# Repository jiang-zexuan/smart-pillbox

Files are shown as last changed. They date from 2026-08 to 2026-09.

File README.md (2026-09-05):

# 自动分药系统（Smart Pillbox）

基于 STM32 的自动分药系统，由 Android 应用、STM32 固件、Bluetooth SPP/RFCOMM 通信和参数化外壳组成。仓库包含 CadQuery/Python 参数化模型源文件及 STEP/STL 三维模型。

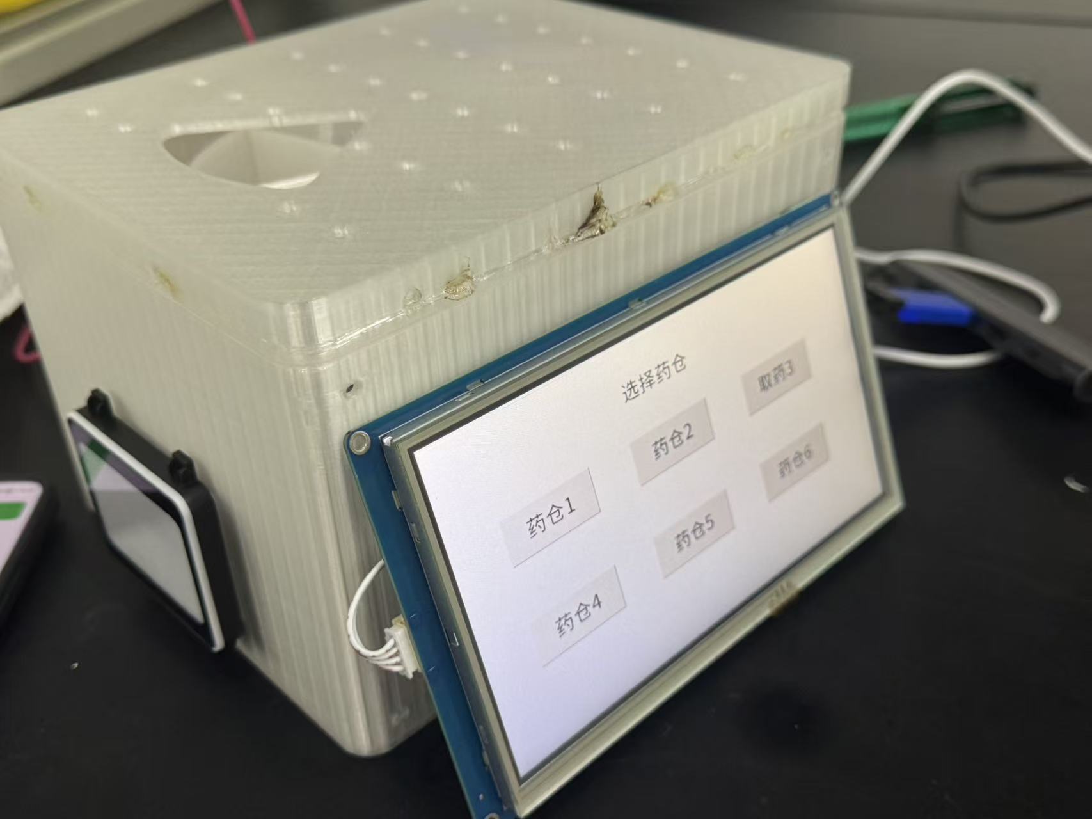
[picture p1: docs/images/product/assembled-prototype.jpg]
实物原型


## 实物与结构展示

### 实物原型

系统装配完成后的整体外观，包含分药转盘、显示屏和扫码区域。

自动分药系统实物原型

### 外壳打印

参数化外壳的打印与装配效果。

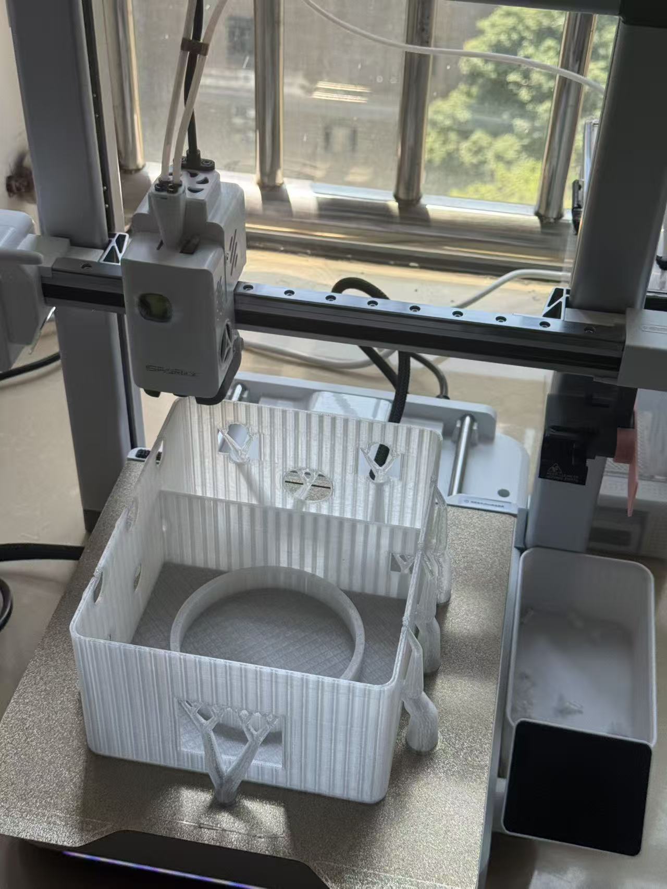
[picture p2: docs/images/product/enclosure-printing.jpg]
自动分药系统外壳打印


### 内部电子器件

内部控制板、蓝牙模块、称重模块及其他外设的安装状态。

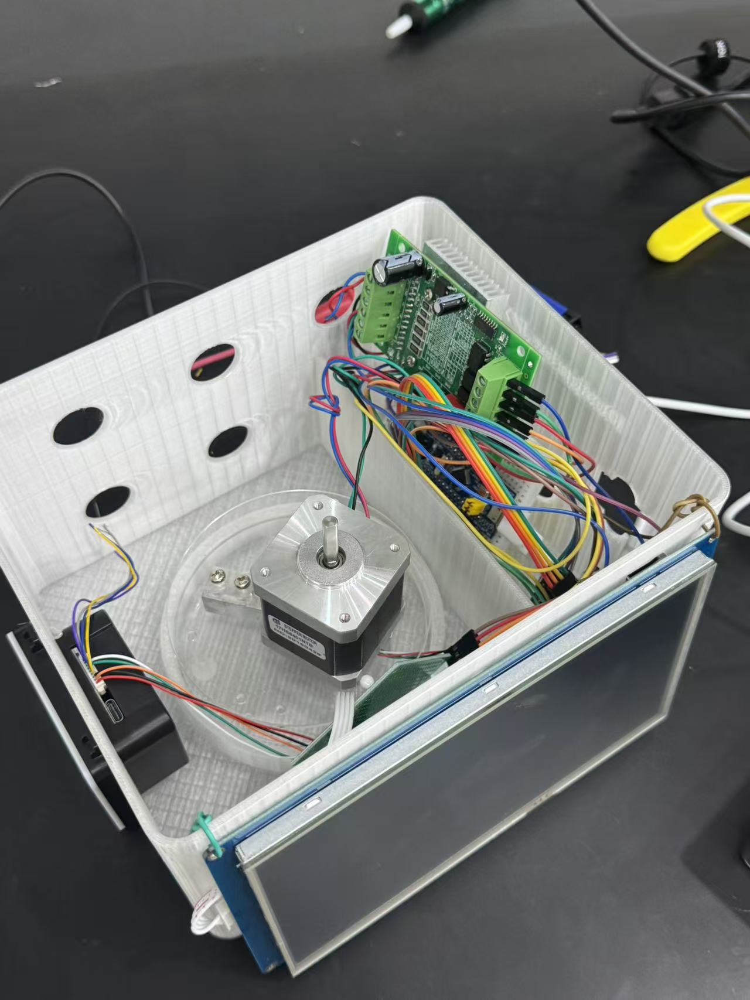
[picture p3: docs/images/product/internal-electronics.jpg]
自动分药系统内部电子器件


### 三维结构总览

CAD 模型展示系统整体结构与各部件的空间关系。

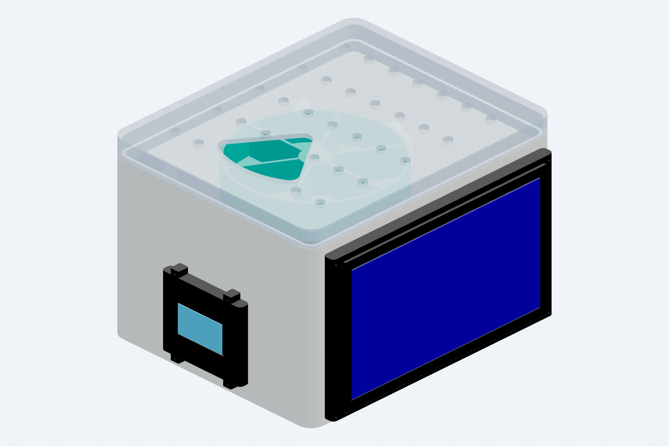
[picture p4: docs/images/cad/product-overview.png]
自动分药系统三维结构总览


### 正面扫码与显示区域

正面视图展示 QR100 扫码器、显示屏和人机交互区域。

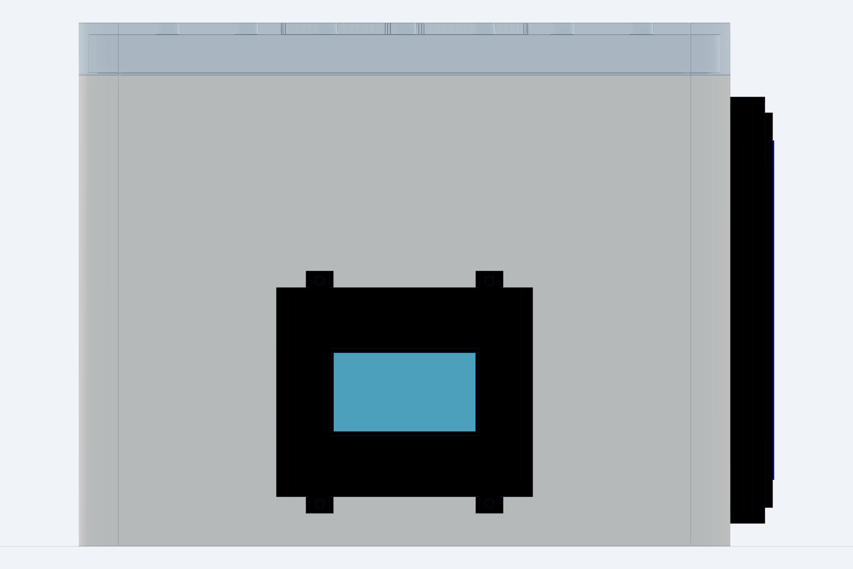
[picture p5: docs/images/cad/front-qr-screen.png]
自动分药系统正面扫码与显示区域


### 内部布局

CAD 剖视布局展示转盘、电子器件与外壳内部的安装关系。

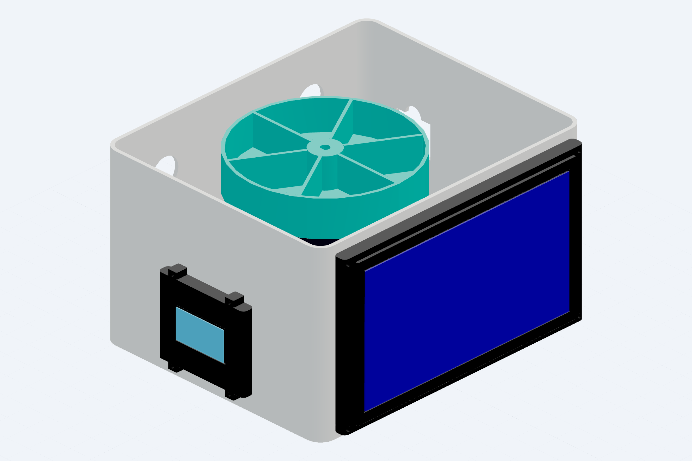
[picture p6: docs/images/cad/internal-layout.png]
自动分药系统内部布局


## 系统组成

系统由 Android 应用、STM32 固件、Bluetooth SPP/RFCOMM 通信链路和参数化外壳构成，实现定时提醒、自动出药、称重检测、漏服记录与手机端管理等完整功能。

## 核心功能

- Android `BleManager` 基于标准 SPP UUID，通过 RFCOMM Socket 完成蓝牙扫描、连接、自动重连与分行数据收发，下发 `TIME`、`PLAN`、`SET`、`MOTOR`、`SYNC` 五类控制命令。
- STM32 固件 `src/protocol.c` 实现命令解析与分派，驱动 HMI/OLED 显示、QR100 扫码、HX711 称重、蜂鸣器提醒和步进电机出药机构。
- 步进电机转盘支持 6 仓位定位，采用最短路径算法与相对位置追踪。
- HX711 称重模块通过滑动平均滤波与零点校准实现取药检测，重量下降超过阈值即判定为已服药。
- 服药记录持久化存储于 STM32 内部 Flash，循环写入并带校验和，上电自动恢复。
- PlatformIO 支持 `bluepill_f103c8` 固件构建，配套电机命令静态检查脚本与仓库规范单元测试。

## 目录结构

| 路径 | 内容 |
| --- | --- |
| `android/` | Android Studio/Gradle 应用源码（Kotlin）。 |
| `firmware/` | STM32Cube HAL、PlatformIO 工程、通信协议与外设驱动源码。 |
| `mechanical/src/` | CadQuery/Python 参数化模型源文件。 |
| `mechanical/models/` | STEP/STL 三维模型文件，可直接用于 3D 打印。 |
| `docs/` | [系统架构](docs/architecture.md)、[通信协议](docs/protocol.md) 及配图。 |
| `tests/` | 仓库规范检查脚本与单元测试。 |

## 构建与验证

### 固件构建（PlatformIO）

```powershell
cd firmware
pio run
python tools_check_motor_command.py
```

### Android 应用构建

需配置 JDK 与 Android SDK 环境后执行：

```powershell
cd android
.\gradlew.bat test
```

### 仓库规范检查

```powershell
python -m unittest discover -s tests -v
```

固件构建、电机命令静态检查与全部 6 项仓库规范单元测试均通过。

## 许可证与版权

软件源码（`android/`、`firmware/`）采用 MIT License；硬件/CAD（`mechanical/`）采用 CERN-OHL-P-2.0。完整法律文本在 [`LICENSES/`](LICENSES/)。实物照片和说明文字由作者保留版权，除非另有书面许可。

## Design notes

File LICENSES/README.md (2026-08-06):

# 许可证说明

- 软件源码（`android/`、`firmware/`）采用 MIT License，完整文本见 [MIT.txt](MIT.txt)。
- 硬件相关源码与 CAD 模型（`mechanical/`）采用 CERN Open Hardware Licence Version 2 - Permissive，完整文本见 [CERN-OHL-P-2.0.txt](CERN-OHL-P-2.0.txt)。
- `docs/images/product/` 中的实物照片以及项目说明文字为作者保留版权，除非另有书面授权，不随上述软件/硬件许可证自动授予再利用权。

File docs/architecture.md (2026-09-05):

# 系统架构

自动分药系统由 Android 应用、经典蓝牙串口链路和 STM32 固件组成。应用通过 Bluetooth SPP 的 RFCOMM socket 与 JDY-31 类串口蓝牙模块通信；模块的 UART 接到 STM32。固件再驱动屏幕、人机界面、二维码扫描器、蜂鸣器、HX711 称重和步进电机。

```text
Android UI / 本地存储
        |
        | Bluetooth SPP (RFCOMM, UUID 00001101-0000-1000-8000-00805F9B34FB)
        v
JDY-31 经典蓝牙串口模块
        |
        | UART, CRLF 分行文本
        v
STM32F103C8T6 firmware
        +--> TJC8048X270 HMI / OLED
        +--> QR100 scanner
        +--> HX711 load-cell sensor
        +--> buzzer and stepper motor
```

## 数据流

应用负责扫描/选择设备、建立 RFCOMM socket、按 CRLF 发送命令并解析回执。固件在主循环中逐行读取 UART，交给 `src/protocol.c` 分派；状态、服药记录和提醒通过同一链路回传。系统时间由应用通过 `TIME` 命令同步，同时支持切换为 DS3231 硬件 RTC。

## 构建边界

- Android：`android/` 是 Gradle Android application，目标 SDK 34，最低 SDK 24。
- Firmware：`firmware/platformio.ini` 使用 `bluepill_f103c8`、STM32Cube framework；`Core/` 与 `Drivers/` 是 HAL/CubeMX 支持树，`include/src` 是 PlatformIO 当前编译入口。
- Mechanical：`mechanical/src/` 保存 CadQuery/Python 参数化模型源，`mechanical/models/` 包含发布用 STEP/STL 输出。

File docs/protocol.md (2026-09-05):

# 串口协议

传输为 Bluetooth SPP/RFCOMM 字节流，Android 每条命令追加 `\\r\\n`，STM32 按行解析。下表列出 Android 与 STM32 源码中使用的业务命令。

| 命令 | 格式 | 固件行为 / 回执 |
| --- | --- | --- |
| `TIME` | `TIME:<unix_timestamp>` | 设置软件时钟；回 `TIME_ACK:<timestamp>`。 |
| `PLAN` | `PLAN:<slot>,<hh>,<mm>,<period>,<enabled>` | 校验 6 个仓位、时间和时段，保存计划；回 `PLAN_ACK:...`。 |
| `SET` | `SET:<slot>,<medicine_name>` | 写入药品名称并更新仓位状态；回 `SET_ACK:...`，启用电机时还回 `MOTOR_ACK:SET_SLOT,...`。 |
| `MOTOR` | `MOTOR:TEST`、`MOTOR:SLOT,<slot>`、`MOTOR:CW,<steps>`、`MOTOR:CCW,<steps>` | 在 `FEATURE_MOTOR_RESERVED=1` 时执行步进测试、转到仓位或按方向步进；回 `MOTOR_ACK:...`。源码将步数限制为 1..6400。 |
| `SYNC` | `SYNC:ALL` | 请求全量状态；固件调用 `BLE_SendStatus()` 回传状态/计划/仓位。 |

其它源码中出现的 `PING`、`TEST`、`BEEP`、`TARE`、`STAT`、`QR`、`REMIND`、`ALERT`、`REC` 属于心跳、调试或设备内部事件，不作为跨模块业务 API。

## 示例

```text
TIME:1780000000\r\n
PLAN:0,8,30,0,1\r\n
SET:0,Vitamin-C\r\n
MOTOR:SLOT,0\r\n
SYNC:ALL\r\n
```

协议采用 CRLF 分行文本格式，便于调试与跨平台解析；调用方应处理无回执、格式错误和设备断连等异常场景。

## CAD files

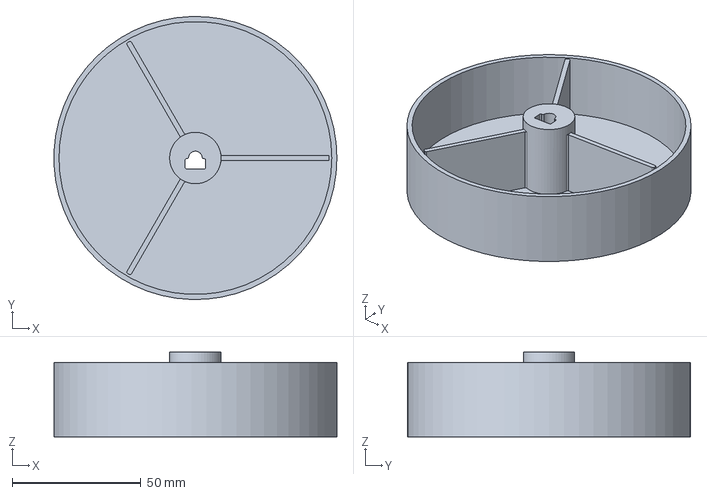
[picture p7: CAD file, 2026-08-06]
mechanical/models/smart_pillbox_turntable.step
109.9 x 110.0 x 33.0 mm

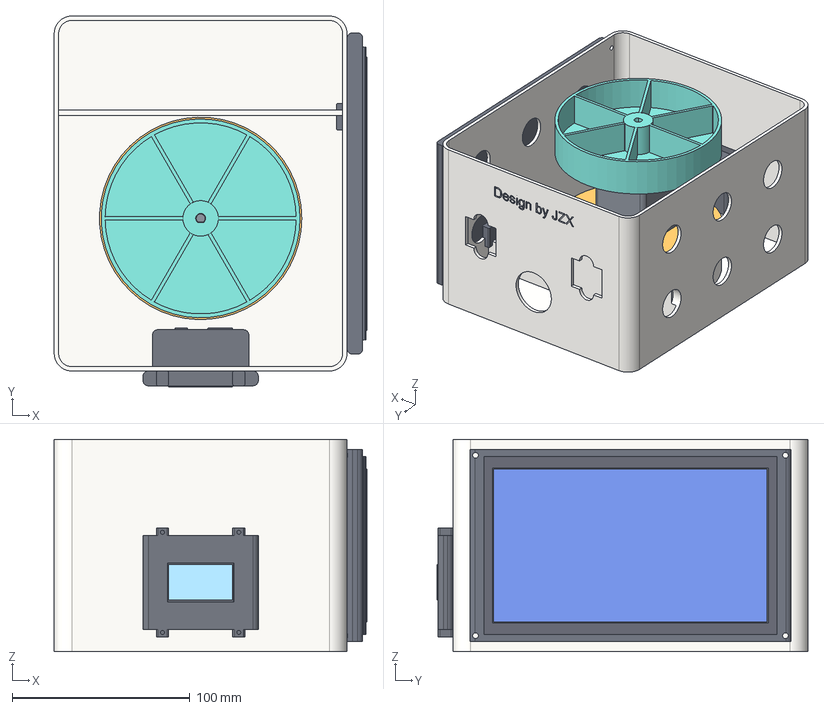
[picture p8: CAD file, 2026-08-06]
mechanical/models/smart_pillbox_colored_internal_no_lid.step
176.1 x 209.0 x 119.5 mm
warm_white_printed_base
silver_hx711_load_sensor_cylinder
amber_downward_open_motor_mount
graphite_nema17_stepper_motor
metallic_d_shaft_visual_overlay
teal_six_compartment_medicine_tray
black_zy_qr100_scanner
cyan_qr100_scan_window
dark_tjc8048x270_serial_screen
black_screen_bezel_overlay
blue_active_display_overlay

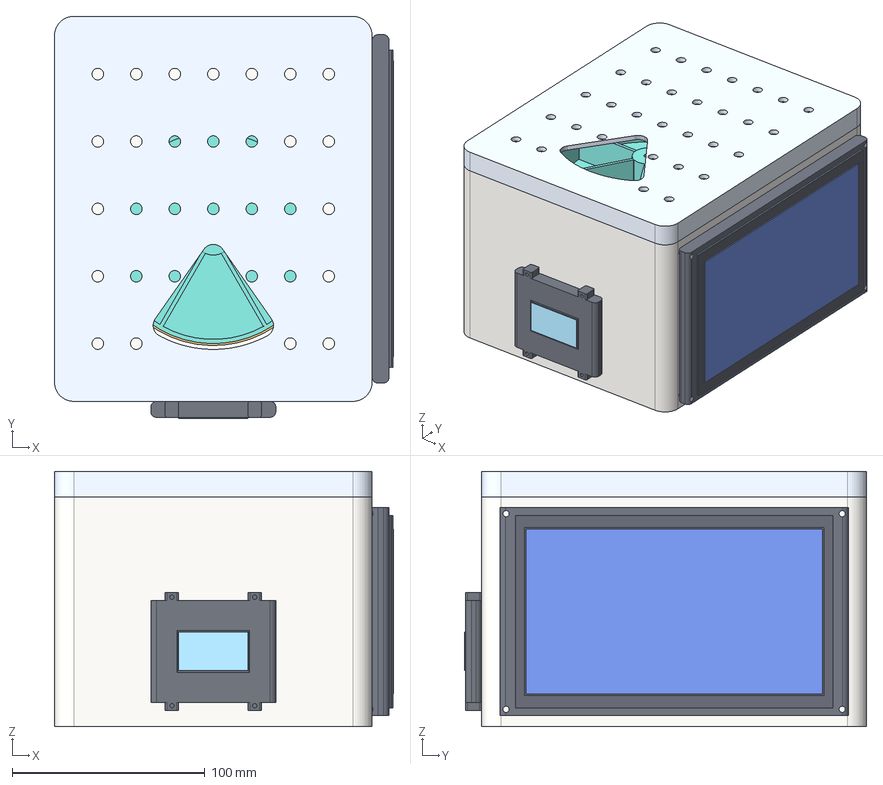
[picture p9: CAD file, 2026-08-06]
mechanical/models/smart_pillbox_colored_product_render.step
176.1 x 209.0 x 132.5 mm
warm_white_printed_base
silver_hx711_load_sensor_cylinder
amber_downward_open_motor_mount
graphite_nema17_stepper_motor
metallic_d_shaft_visual_overlay
teal_six_compartment_medicine_tray
pale_blue_raised_top_lid
black_zy_qr100_scanner
cyan_qr100_scan_window
dark_tjc8048x270_serial_screen
black_screen_bezel_overlay
blue_active_display_overlay

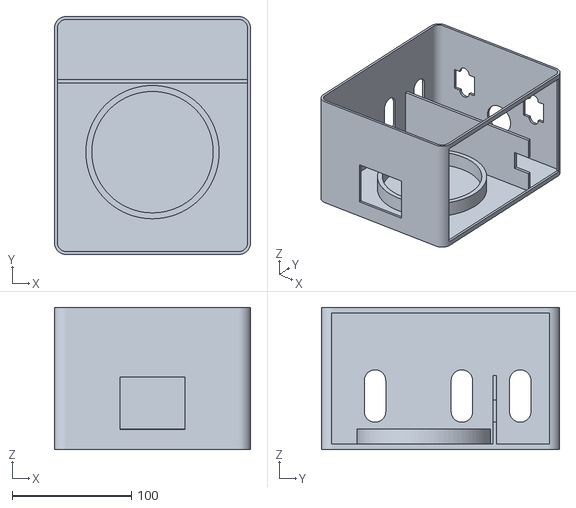
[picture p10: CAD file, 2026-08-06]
mechanical/models/smart_pillbox_base_lightweight_with_screen_opening.stl
165.0 x 200.0 x 119.5

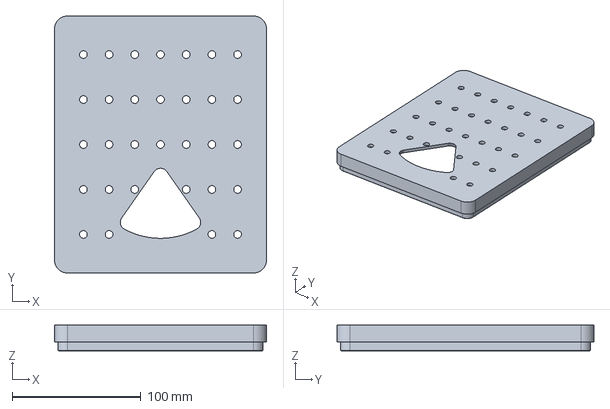
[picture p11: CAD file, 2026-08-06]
mechanical/models/smart_pillbox_top_lid.step
165.0 x 200.0 x 20.0 mm

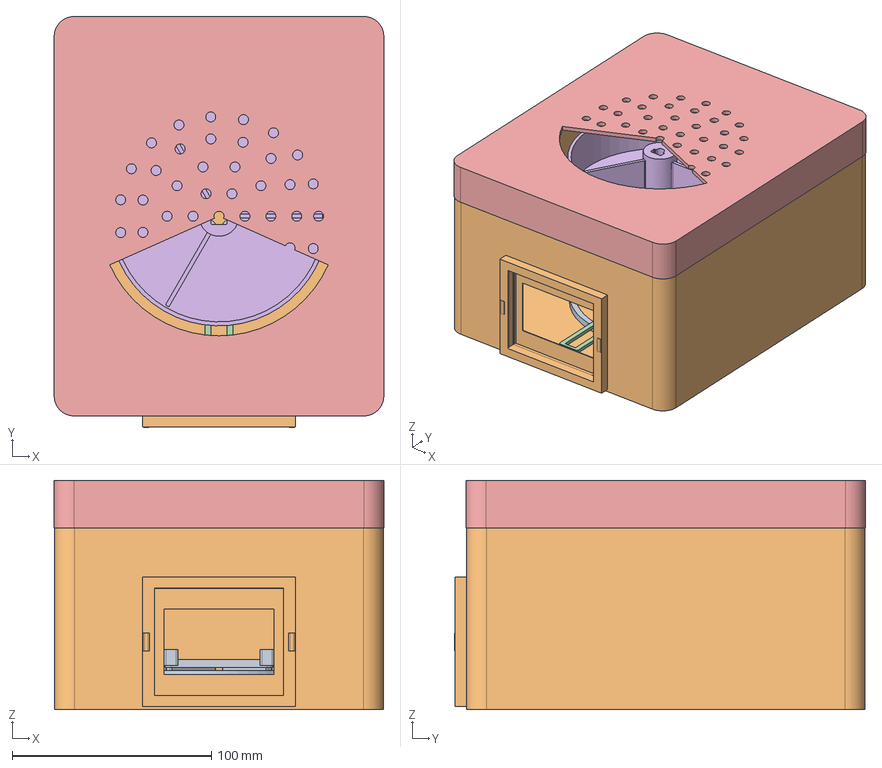
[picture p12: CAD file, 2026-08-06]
mechanical/models/smart_pillbox_printable.step
165.4 x 206.2 x 115.0 mm
base
lid
turntable

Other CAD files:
mechanical/models/smart_pillbox_top_lid.stl
mechanical/models/smart_pillbox_turntable.stl

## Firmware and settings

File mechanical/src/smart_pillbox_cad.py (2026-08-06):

"""
Smart pillbox CAD model.
Units: millimeters.
Coordinate system: origin at enclosure footprint center; X width left/right, Y depth front/back, Z up.

This file is generated for the smart pillbox course-design enclosure.
It exposes gen_step() for the full placeholder assembly.  Additional helper
functions are used by small wrapper files to export pure printable assembly
and individual printable parts.
"""
from __future__ import annotations

import inspect
import math
import platform

# Work around a build123d Windows font scan issue caused by malformed system fonts.
_REAL_PLATFORM_SYSTEM = platform.system

def _platform_system_patch():
    for fr in inspect.stack()[:10]:
        if fr.filename.replace("\\", "/").endswith("build123d/text.py"):
            return "Linux"
    return _REAL_PLATFORM_SYSTEM()

platform.system = _platform_system_patch

from build123d import *  # noqa: E402,F403
from cadpy.assembly import AssemblyHelper, label_shape  # noqa: E402

# -------------------------- Parameters --------------------------
OUTER_X = 165.0
OUTER_Y = 200.0
OUTER_Z = 115.0
WALL = 2.5
CLEARANCE = 0.4
CORNER_R = 10.0

BASE_H = 92.0
LID_H = 24.0
LID_SKIRT_H = 10.0
LID_TOP_TH = 3.0
LID_OVERLAP = 0.4

FRONT_Y = -OUTER_Y / 2
BACK_Y = OUTER_Y / 2

# QR100, based on the provided manual.
QR_FACE_W = 65.0
QR_FACE_H = 53.0
QR_FACE_TH = 8.3
QR_BODY_W = 54.3
QR_BODY_H = 31.8
QR_BODY_DEPTH = 65.3
QR_RECESS_CLEAR = 0.6
QR_BODY_CLEAR = 0.8
QR_CENTER_Z = 34.0

# Dispense window.
DISP_W = 70.0
DISP_H = 35.0
DISP_CENTER_Z = 72.0

# Cable hole.
CABLE_D = 25.0
CABLE_CENTER_Z = 35.0

# Scale / motor / turntable stack.
SCALE_D = 100.0
SCALE_TH = 3.5
SCALE_Z = 9.0
ISLAND_D = 82.0
ISLAND_H = 7.0
ISLAND_Z = SCALE_Z + SCALE_TH / 2 + ISLAND_H / 2 + 0.8
MOTOR_X = 42.3
MOTOR_BODY_H = 48.0
MOTOR_SLOT = 43.5
MOTOR_Z = ISLAND_Z + ISLAND_H / 2 + MOTOR_BODY_H / 2
MOTOR_SHAFT_D = 5.0
MOTOR_SHAFT_H = 22.0
SHAFT_Z = ISLAND_Z + ISLAND_H / 2 + MOTOR_BODY_H + MOTOR_SHAFT_H / 2
TURNTABLE_D = 110.0
TURNTABLE_H = 29.0
TRAY_FLOOR = 4.0
TRAY_WALL = 2.0
TRAY_Z = ISLAND_Z + ISLAND_H / 2 + MOTOR_BODY_H + 7.0 + TURNTABLE_H / 2

# Rear electronics bay.
E_BAY_W = 130.0
E_BAY_D = 42.0
E_BAY_H = 32.0
E_BAY_CENTER_Y = 58.0
E_BAY_CENTER_Z = 27.0

# Visualization colors.
COL_BASE = Color(0.84, 0.86, 0.88, 1.0)
COL_LID = Color(0.92, 0.93, 0.95, 1.0)
COL_TRAY = Color(0.95, 0.95, 0.88, 1.0)
COL_SCALE = Color(0.55, 0.75, 0.95, 0.55)
COL_MOTOR = Color(0.1, 0.1, 0.1, 0.7)
COL_METAL = Color(0.75, 0.75, 0.75, 0.85)
COL_QR = Color(0.05, 0.05, 0.05, 0.85)
COL_BOARD = Color(0.05, 0.55, 0.25, 0.65)


def _rounded_box(x: float, y: float, z: float, r: float, label: str | None = None, center=(0, 0, 0)):
    """Create a rounded rectangular solid with coordinates baked into geometry."""
    with BuildPart() as part:
        with Locations(center):
            Box(x, y, z)
        edges = part.edges().filter_by(Axis.Z)
        if r > 0:
            fillet(edges, radius=min(r, x / 2 - 0.2, y / 2 - 0.2))
    obj = part.part
    if label:
        obj.label = label
    return obj


def _translated(shape, x=0, y=0, z=0):
    # build123d shapes compose reliably with Location multiplication.
    return Location((x, y, z)) * shape
def _base_solid(include_cutouts: bool = True):
    """Bottom enclosure with open top and front/back cutouts."""
    zc = BASE_H / 2
    with BuildPart() as p:
        # main rounded shell block
        add(_translated(_rounded_box(OUTER_X, OUTER_Y, BASE_H, CORNER_R), z=zc))
        # hollow top cavity, leaving side walls and bottom floor
        add(_translated(Box(OUTER_X - 2 * WALL, OUTER_Y - 2 * WALL, BASE_H - WALL + 2), z=WALL + (BASE_H - WALL + 2) / 2), mode=Mode.SUBTRACT)
        # front dispense opening
        add(_translated(Box(DISP_W, WALL + 6, DISP_H), y=FRONT_Y, z=DISP_CENTER_Z), mode=Mode.SUBTRACT)
        # QR face shallow step recess on front lower panel
        add(_translated(Box(QR_FACE_W + QR_RECESS_CLEAR, WALL + 1.2, QR_FACE_H + QR_RECESS_CLEAR), y=FRONT_Y - 0.1, z=QR_CENTER_Z), mode=Mode.SUBTRACT)
        # QR smaller through/body clearance into enclosure
        add(_translated(Box(QR_BODY_W + QR_BODY_CLEAR, QR_BODY_DEPTH + 5, QR_BODY_H + QR_BODY_CLEAR), y=FRONT_Y + QR_BODY_DEPTH / 2, z=QR_CENTER_Z), mode=Mode.SUBTRACT)
        # rear cable hole, horizontal cylinder through back wall
        add(_translated(Cylinder(CABLE_D / 2, WALL + 8, rotation=(90, 0, 0)), y=BACK_Y, z=CABLE_CENTER_Z), mode=Mode.SUBTRACT)
        # rear electronics bay recessed floor/platform pocket, not through wall
        add(_translated(Box(E_BAY_W + 2, E_BAY_D + 2, E_BAY_H), y=E_BAY_CENTER_Y, z=E_BAY_CENTER_Z), mode=Mode.SUBTRACT)
        # scale recess pocket in bottom interior
        add(_translated(Cylinder(SCALE_D / 2 + 2, SCALE_TH + 1), z=SCALE_Z), mode=Mode.SUBTRACT)
        # add a front lip around QR to show outer frame support
        add(_translated(_rounded_box(QR_FACE_W + 7, 3.0, QR_FACE_H + 7, 3.0), y=FRONT_Y - 1.0, z=QR_CENTER_Z))
        add(_translated(Box(QR_FACE_W + QR_RECESS_CLEAR, 5.0, QR_FACE_H + QR_RECESS_CLEAR), y=FRONT_Y - 1.2, z=QR_CENTER_Z), mode=Mode.SUBTRACT)
        # add thin shelf under dispense opening for visual support
        add(_translated(_rounded_box(DISP_W + 12, 7.0, 3.0, 2.0), y=FRONT_Y + 3.0, z=DISP_CENTER_Z - DISP_H / 2 - 3.0))
    obj = p.part
    obj.label = "base_print_part"
    obj.color = COL_BASE
    return obj


def _lid_solid():
    """Friction-fit lid with perforation array over tray area."""
    lid_center_z = BASE_H + LID_H / 2 - 1.0
    with BuildPart() as p:
        add(_translated(_rounded_box(OUTER_X + LID_OVERLAP, OUTER_Y + LID_OVERLAP, LID_H, CORNER_R), z=lid_center_z))
        # inner hollow/skirt clearance from bottom, leaves top plate
        inner_h = LID_H - LID_TOP_TH
        add(_translated(_rounded_box(OUTER_X - 2 * WALL + 0.8, OUTER_Y - 2 * WALL + 0.8, inner_h + 1.0, CORNER_R - WALL), z=BASE_H - 1 + inner_h / 2), mode=Mode.SUBTRACT)
        # bottom opening cleanup
        add(_translated(Box(OUTER_X - 4, OUTER_Y - 4, 4), z=BASE_H - 3), mode=Mode.SUBTRACT)
        # perforated observation/vent holes over turntable circular region
        hole_d = 5.0
        for r in [0, 13, 26, 39, 50]:
            count = 1 if r == 0 else max(6, int(2 * math.pi * r / 16))
            for i in range(count):
                ang = 0 if count == 1 else 2 * math.pi * i / count
                x = r * math.cos(ang)
                y = r * math.sin(ang)
                if x * x + y * y <= 52 ** 2:
                    add(_translated(Cylinder(hole_d / 2, LID_TOP_TH + 4), x=x, y=y, z=BASE_H + LID_H - LID_TOP_TH / 2), mode=Mode.SUBTRACT)
        # front clearance notch above dispense zone so lid doesn't block hand access
        add(_translated(Box(DISP_W + 8, 10, 18), y=FRONT_Y + 2, z=BASE_H + 2), mode=Mode.SUBTRACT)
    obj = p.part
    obj.label = "lid_print_part"
    obj.color = COL_LID
    return obj


def _turntable_solid():
    """110 mm diameter three-sector tray with D-shaped motor shaft hole."""
    with BuildPart() as p:
        # disk floor
        Cylinder(TURNTABLE_D / 2, TRAY_FLOOR)
        # outer rim
        add(Cylinder(TURNTABLE_D / 2, TURNTABLE_H), mode=Mode.ADD)
        add(Cylinder(TURNTABLE_D / 2 - TRAY_WALL, TURNTABLE_H + 1), mode=Mode.SUBTRACT)
        # restore floor after shell subtraction
        add(Cylinder(TURNTABLE_D / 2 - TRAY_WALL, TRAY_FLOOR), mode=Mode.ADD)
        # three radial divider walls
        for ang in [0, 120, 240]:
            divider = Pos((TURNTABLE_D/4)*math.cos(math.radians(ang)), (TURNTABLE_D/4)*math.sin(math.radians(ang)), TURNTABLE_H/2) * Box(TURNTABLE_D/2 - 6, TRAY_WALL, TURNTABLE_H)
            divider = Rot(0, 0, ang) * divider
            add(divider)
        # center hub
        add(Cylinder(10, TURNTABLE_H + 4))
        # D-shaped shaft cut: round plus flat-side clipping box
        add(Cylinder(5.3 / 2, TURNTABLE_H + 8), mode=Mode.SUBTRACT)
        add(_translated(Box(6, 3, TURNTABLE_H + 10), y=-2.65 + 0.4), mode=Mode.SUBTRACT)
        # soften only vertical outer/hub edges a little
        try:
            fillet(p.edges().filter_by(Axis.Z), radius=0.8)
        except Exception:
            pass
    obj = p.part
    obj.label = "three_sector_turntable_print_part"
    obj.color = COL_TRAY
    return obj


def _scale_placeholder():
    with BuildPart() as p:
        Cylinder(SCALE_D / 2, SCALE_TH)
        # sensor bar on top
        add(_translated(_rounded_box(75, 12, 3.0, 1.0), z=SCALE_TH / 2 + 1.5))
        # small HX connector tab visual
        add(_translated(_rounded_box(20, 12, 2, 1), x=34, y=0, z=SCALE_TH / 2 + 2.5))
    obj = p.part
    obj.label = "100mm_round_scale_placeholder"
    obj.color = COL_SCALE
    return obj


def _bearing_island_and_motor_slot():
    with BuildPart() as p:
        Cylinder(ISLAND_D / 2, ISLAND_H)
        # 43x43 motor shallow location pocket with raised rim/edge blocks
        add(_translated(_rounded_box(MOTOR_SLOT + 7, MOTOR_SLOT + 7, 4.0, 3), z=ISLAND_H / 2 + 2.0))
        add(_translated(_rounded_box(MOTOR_SLOT, MOTOR_SLOT, 5.0, 2.2), z=ISLAND_H / 2 + 3.2), mode=Mode.SUBTRACT)
        # central cable/shaft relief
        add(Cylinder(8, ISLAND_H + 8), mode=Mode.SUBTRACT)
    obj = p.part
    obj.label = "isolated_load_island_with_motor_cradle"
    obj.color = Color(0.7, 0.7, 0.72, 1)
    return obj


def _motor_placeholder():
    with BuildPart() as p:
        add(_rounded_box(MOTOR_X, MOTOR_X, MOTOR_BODY_H, 4.5))
        # top metal flange
        add(_translated(_rounded_box(42.3, 42.3, 4.0, 3.0), z=MOTOR_BODY_H / 2 + 2.0))
        # front shaft boss and shaft
        add(_translated(Cylinder(11, 4.0), z=MOTOR_BODY_H / 2 + 6.0))
        add(_translated(Cylinder(MOTOR_SHAFT_D / 2, MOTOR_SHAFT_H), z=MOTOR_BODY_H / 2 + 6.0 + MOTOR_SHAFT_H / 2))
        # connector protrusion at front-left visual side
        add(_translated(_rounded_box(18, 8, 8, 1.0), x=0, y=-MOTOR_X / 2 - 3, z=-MOTOR_BODY_H / 2 + 12))
    obj = p.part
    obj.label = "nema17_stepper_placeholder"
    obj.color = COL_MOTOR
    return obj


def _qr100_placeholder():
    with BuildPart() as p:
        # front face flange, centered on local origin with depth along Y
        add(_rounded_box(QR_FACE_W, QR_FACE_TH, QR_FACE_H, 4.0))
        # body extends inward (+Y from front panel)
        add(_translated(_rounded_box(QR_BODY_W, QR_BODY_DEPTH - QR_FACE_TH, QR_BODY_H, 3.0), y=(QR_BODY_DEPTH - QR_FACE_TH)/2 + QR_FACE_TH/2))
        # scanner window inset on face
        add(_translated(_rounded_box(40, 2.0, 24, 3.0), y=-QR_FACE_TH/2 - 0.8), mode=Mode.ADD)
    obj = p.part
    obj.label = "qr100_scanner_placeholder"
    obj.color = COL_QR
    return obj


def _electronics_placeholders():
    with BuildPart() as p:
        # generic controller board
        add(_translated(_rounded_box(80, 32, 2, 1.5), y=0, z=8))
        # battery pack block
        add(_translated(_rounded_box(70, 24, 18, 4), y=0, z=-5))
        # HX711 board
        add(_translated(_rounded_box(34, 22, 2, 1.2), x=45, y=0, z=8))
    obj = p.part
    obj.label = "rear_electronics_bay_placeholders"
    obj.color = COL_BOARD
    return obj


def printable_parts():
    return {
        "base": _base_solid(),
        "lid": _lid_solid(),
        "turntable": _turntable_solid(),
    }


def printable_assembly():
    asm = AssemblyHelper("smart_pillbox_printable_assembly")
    parts = printable_parts()
    asm.add(parts["base"], "base_print_part")
    asm.add(parts["lid"], "lid_print_part")
    asm.add(_translated(parts["turntable"], z=TRAY_Z), "three_sector_turntable_print_part")
    return asm.compound(asm.children)


def full_assembly_with_placeholders():
    asm = AssemblyHelper("smart_pillbox_with_hardware_placeholders")
    parts = printable_parts()
    asm.add(parts["base"], "base_print_part")
    asm.add(parts["lid"], "lid_print_part")
    asm.add(_translated(parts["turntable"], z=TRAY_Z), "three_sector_turntable_print_part")
    asm.add(_translated(_scale_placeholder(), z=SCALE_Z), "100mm_round_scale_placeholder")
    asm.add(_translated(_bearing_island_and_motor_slot(), z=ISLAND_Z), "isolated_load_island_with_motor_cradle")
    asm.add(_translated(_motor_placeholder(), z=MOTOR_Z), "nema17_stepper_placeholder")
    # QR100 in front lower panel. Its local front face points toward -Y; body extends +Y into enclosure.
    asm.add(_translated(_qr100_placeholder(), y=FRONT_Y + QR_FACE_TH / 2, z=QR_CENTER_Z), "qr100_scanner_placeholder")
    asm.add(_translated(_electronics_placeholders(), y=E_BAY_CENTER_Y, z=E_BAY_CENTER_Z), "rear_electronics_bay_placeholders")
    return asm.compound(asm.children)


def gen_step():
    """Default CAD skill entrypoint: full assembly including hardware placeholders."""
    return full_assembly_with_placeholders()


if __name__ == "__main__":
    # Quick local smoke-test dimensions.
    shape = gen_step()
    bb = shape.bounding_box()
    print("bbox", bb.size)

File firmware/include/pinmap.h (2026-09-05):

/**
 * @file    pinmap.h
 * @brief   STM32F103C8T6 引脚映射表（LQFP-48）
 *
 * ┌────────────┬──────────┬─────────────────────┐
 * │ 外设        │ STM32外设 │ 引脚                 │
 * ├────────────┼──────────┼─────────────────────┤
 * │ 串口屏/调试   │ USART1   │ PA9(TX) PA10(RX)   │
 * │ JDY-31 蓝牙 │ USART2   │ PA2(TX) PA3(RX)    │
 * │ QR100扫码   │ USART3   │ PB10(TX) PB11(RX)  │
 * │ OLED/RTC    │ I²C1     │ PB8(SCL) PB9(SDA)  │
 * │ 步进电机     │ TIM2 PWM │ PA0(PUL) PA1(DIR) PA4(EN) │
 * │ HX711 称重  │ GPIO     │ PB0(SCK) PB1(DOUT) │
 * │ 蜂鸣器       │ GPIO     │ PA5                │
 * │ 光电传感器   │ GPIO EXTI│ PB12 PB13          │
 * │ LED         │ GPIO     │ PC13(板载) PB14(蓝牙) │
 * │ SWD调试     │ SWD      │ PA13(SWDIO) PA14(SWCLK) │
 * └────────────┴──────────┴─────────────────────┘
 */

#ifndef __PINMAP_H
#define __PINMAP_H

/* ==================== USART1 — TJC 串口屏 / USB-TTL 调试 ==================== */
#define HMI_USART               USART1
#define HMI_TX_PORT             GPIOA
#define HMI_TX_PIN              GPIO_PIN_9
#define HMI_RX_PORT             GPIOA
#define HMI_RX_PIN              GPIO_PIN_10
#define HMI_BAUDRATE            9600    /* 淘晶驰出厂115200 */

/* ==================== USART2 — JDY-31 蓝牙 ==================== */
#define BLE_USART               USART2
#define BLE_TX_PORT             GPIOA
#define BLE_TX_PIN              GPIO_PIN_2
#define BLE_RX_PORT             GPIOA
#define BLE_RX_PIN              GPIO_PIN_3
#define BLE_BAUDRATE            9600      /* JDY-31 出厂9600 */

/* ==================== USART3 — QR100 条码/二维码扫描模块 ==================== */
#define QR100_USART             USART3
#define QR100_TX_PORT           GPIOB
#define QR100_TX_PIN            GPIO_PIN_10
#define QR100_RX_PORT           GPIOB
#define QR100_RX_PIN            GPIO_PIN_11
#define QR100_BAUDRATE          9600      /* 常见默认值；若模块为115200请改这里 */

/* ==================== USART3 — DY-SV17F 语音模块（可选） ==================== */
#define VOICE_USART             USART3
#define VOICE_TX_PORT           GPIOB
#define VOICE_TX_PIN            GPIO_PIN_10
#define VOICE_RX_PORT           GPIOB
#define VOICE_RX_PIN            GPIO_PIN_11
#define VOICE_BAUDRATE          9600

/* ==================== I²C1 — DS3231 RTC + SSD1306 OLED ============ */
/* 注意：使用 I2C1 Remap 将 SCL/SDA 从 PB6/PB7 移到 PB8/PB9         */
/*       调用 I2C 前必须 __HAL_AFIO_REMAP_I2C1_ENABLE()             */
#define RTC_I2C                 I2C1
#define RTC_SCL_PORT            GPIOB
#define RTC_SCL_PIN             GPIO_PIN_8   /* PB8 = I2C1_SCL (remap) */
#define RTC_SDA_PORT            GPIOB
#define RTC_SDA_PIN             GPIO_PIN_9   /* PB9 = I2C1_SDA (remap) */
#define DS3231_ADDR             0xD0         /* 7-bit 0x68 << 1 */

/* ==================== TB6560 电机（TIM2） ==================== */
#define MOTOR_TIM               TIM2
#define MOTOR_TIM_CHANNEL       TIM_CHANNEL_1
#define MOTOR_PUL_PORT          GPIOA      /* PA0 = TIM2_CH1 */
#define MOTOR_PUL_PIN           GPIO_PIN_0
#define MOTOR_DIR_PORT          GPIOA      /* PA1 = GPIO */
#define MOTOR_DIR_PIN           GPIO_PIN_1
#define MOTOR_EN_PORT           GPIOA      /* PA4 = GPIO */
#define MOTOR_EN_PIN            GPIO_PIN_4
#define MOTOR_PWM_FREQ_HZ       800      /* 10kHz 脉冲 */
#define MOTOR_MICROSTEPS        1          /* Driver full-step细分 */
#define MOTOR_STEPS_PER_REV     (200 * MOTOR_MICROSTEPS) /* 3200步/圈 */

/* ==================== HX711 称重传感器 ==================== */
#define HX711_SCK_PORT          GPIOB      /* PB0 */
#define HX711_SCK_PIN           GPIO_PIN_0
#define HX711_DOUT_PORT         GPIOB      /* PB1 */
#define HX711_DOUT_PIN          GPIO_PIN_1

/* ==================== ITR9606 槽型光电开关 ==================== */
#define OPTICAL1_PORT           GPIOB      /* PB12 — 取药通道 */
#define OPTICAL1_PIN            GPIO_PIN_12
#define OPTICAL2_PORT           GPIOB      /* PB13 — 转盘零位 */
#define OPTICAL2_PIN            GPIO_PIN_13

/* ==================== LED ==================== */
#define LED_BUILTIN_PORT        GPIOC      /* PC13 — F103板载LED（低电平亮） */
#define LED_BUILTIN_PIN         GPIO_PIN_13
#define LED_BLE_PORT            GPIOB      /* PB14 — 蓝牙状态灯 */
#define LED_BLE_PIN             GPIO_PIN_14

/* ==================== 蜂鸣器 ==================== */
#define BUZZER_PORT             GPIOA      /* PA5 */
#define BUZZER_PIN              GPIO_PIN_5

#endif /* __PINMAP_H */

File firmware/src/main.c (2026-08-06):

/**
 * @file    main.c
 * @brief   ?????? ? ???????????????
 *
 * ???????JDY-31?HX711?QR100?OLED?TJC????????
 * ???DS3231????????????? feature_config.h ???
 */

#include "main.h"
#include "feature_config.h"
#include "pinmap.h"
#include "ble.h"
#include "protocol.h"
#include "hmi.h"
#include "sensor.h"
#include "record.h"
#include "oled.h"
#include "app_time.h"
#include "buzzer.h"
#include "qr100.h"
#include "debug_uart.h"

#if FEATURE_DS3231_RTC
#include "rtc_ds3231.h"
#endif

#if FEATURE_MOTOR_RESERVED
#include "motor.h"
#endif

#if FEATURE_SERIAL_VOICE
#include "voice.h"
#endif

/* ==================== ???? ==================== */
volatile SystemState g_sys_state = SYS_IDLE;
volatile uint32_t    g_sys_ticks = 0;

MedicineSlot     g_slots[NUM_SLOTS];
MedicationPlan   g_plans[PERIOD_COUNT];
MedicationRecord g_records[128];
uint16_t         g_record_count  = 0;
uint32_t         g_missed_deadline = 0;
uint8_t          g_missed_slot   = 0;

static uint32_t last_hmi_update = 0;
static uint32_t last_led_toggle = 0;
static uint32_t last_ble_debug_tx = 0;
static uint32_t last_hx711_update = 0;
static uint8_t  led_state = 0;
static int32_t  dispense_start_weight = 0;
static uint16_t last_alarm_key = 0xFFFF;

/* ==================== ????? ==================== */

static uint32_t System_Now(void)
{
#if FEATURE_DS3231_RTC
    return RTC_GetTimestamp();
#else
    return AppTime_Now();
#endif
}

static void System_GetHMS(uint8_t *hour, uint8_t *minute, uint8_t *second)
{
#if FEATURE_DS3231_RTC
    DateTime dt;
    RTC_GetDateTime(&dt);
    if (hour) *hour = dt.hour;
    if (minute) *minute = dt.minute;
    if (second) *second = dt.second;
#else
    AppTime_GetHMS(hour, minute, second);
#endif
}

static void System_GetDateTime(AppDateTime *adt)
{
    if (adt == NULL) return;
#if FEATURE_DS3231_RTC
    DateTime dt;
    RTC_GetDateTime(&dt);
    adt->year = 2000U + dt.year;
    adt->month = dt.month;
    adt->day = dt.date;
    adt->hour = dt.hour;
    adt->minute = dt.minute;
    adt->second = dt.second;
#else
    AppTime_GetDateTime(adt);
#endif
}

static bool System_TimeReady(void)
{
#if FEATURE_DS3231_RTC
    return true;
#else
    return AppTime_IsSynced();
#endif
}

/* ==================== GPIO ??? ==================== */

void GPIO_Init(void)
{
    __HAL_RCC_GPIOC_CLK_ENABLE();
    __HAL_RCC_GPIOB_CLK_ENABLE();
    __HAL_RCC_GPIOA_CLK_ENABLE();

    GPIO_InitTypeDef gpio = {0};

    gpio.Mode  = GPIO_MODE_OUTPUT_PP;
    gpio.Pull  = GPIO_NOPULL;
    gpio.Speed = GPIO_SPEED_FREQ_LOW;

    gpio.Pin = LED_BUILTIN_PIN;
    HAL_GPIO_Init(LED_BUILTIN_PORT, &gpio);
    HAL_GPIO_WritePin(LED_BUILTIN_PORT, LED_BUILTIN_PIN, GPIO_PIN_SET);

    gpio.Pin = LED_BLE_PIN;
    HAL_GPIO_Init(LED_BLE_PORT, &gpio);
    HAL_GPIO_WritePin(LED_BLE_PORT, LED_BLE_PIN, GPIO_PIN_RESET);
}

/* ==================== ?????? ==================== */

static void InitDemoData(void)
{
    memset(g_slots, 0, sizeof(g_slots));
    for (int i = 0; i < NUM_SLOTS; i++) {
        g_slots[i].slot_id = i;
        snprintf(g_slots[i].medicine_name, sizeof(g_slots[i].medicine_name), "??%d", i + 1);
        g_slots[i].status = SLOT_EMPTY;
    }
    strcpy(g_slots[0].medicine_name, "????");
    strcpy(g_slots[1].medicine_name, "???");
    strcpy(g_slots[2].medicine_name, "???D");
    g_slots[0].status = SLOT_FILLED;
    g_slots[1].status = SLOT_FILLED;
    g_slots[2].status = SLOT_FILLED;

    memset(g_plans, 0, sizeof(g_plans));
    g_plans[PERIOD_MORNING] = (MedicationPlan){0, 8, 0, PERIOD_MORNING, 1};
    g_plans[PERIOD_NOON]    = (MedicationPlan){1, 12, 30, PERIOD_NOON, 1};
    g_plans[PERIOD_EVENING] = (MedicationPlan){2, 18, 0, PERIOD_EVENING, 0};
    g_plans[PERIOD_EXTRA1]  = (MedicationPlan){3, 8, 30, PERIOD_EXTRA1, 0};
    g_plans[PERIOD_EXTRA2]  = (MedicationPlan){4, 13, 0, PERIOD_EXTRA2, 0};
    g_plans[PERIOD_EXTRA3]  = (MedicationPlan){5, 19, 30, PERIOD_EXTRA3, 0};

    g_record_count = 0;
    g_sys_state = SYS_IDLE;
    g_missed_deadline = 0;
    g_missed_slot = 0;
}

static void System_Init(void)
{
    HAL_Init();
    SystemClock_Config();

    GPIO_Init();
    AppTime_Init();

#if FEATURE_BUZZER
    Buzzer_Init();
#endif

#if FEATURE_DEBUG_UART && !FEATURE_TJC_HMI
    DebugUart_Init();
    DebugUart_Print("\r\n[BOOT] SmartPillbox current-hardware firmware\r\n");
#endif

#if FEATURE_BLE_JDY31
    BLE_Init();
#endif

#if FEATURE_TJC_HMI
    HMI_Init();
#endif

#if FEATURE_QR100
    QR100_Init();
#if FEATURE_DEBUG_UART && !FEATURE_TJC_HMI
    DebugUart_Print("[INIT] QR100 USART3 ready\r\n");
#endif
#endif

#if FEATURE_SERIAL_VOICE
    Voice_Init();
#endif

#if FEATURE_DS3231_RTC
    (void)RTC_Init();
#endif

#if FEATURE_MOTOR_RESERVED
    Motor_Init();
#endif

#if FEATURE_HX711
    Sensor_Init();
#endif

    Record_Init();
    Record_LoadAll();
    InitDemoData();

#if FEATURE_DEBUG_UART && !FEATURE_TJC_HMI
    DebugUart_Print("[INIT] Core modules ready\r\n");
#endif

    __enable_irq();
}

/* ==================== ??/??/?? ==================== */

static void StartDispense(uint8_t slot)
{
    if (slot >= NUM_SLOTS) return;

    g_missed_slot = slot;
    g_missed_deadline = System_Now() + MISSED_TIMEOUT_SECONDS;
    g_sys_state = SYS_DISPENSING;

#if FEATURE_HX711
    HX711_FilterUpdate();
    dispense_start_weight = HX711_ReadWeight();
#endif

#if FEATURE_BUZZER
    Buzzer_Remind10s();
#endif

#if FEATURE_SERIAL_VOICE
    Voice_RemindSlot(slot);
#endif

#if FEATURE_MOTOR_RESERVED
    Motor_GotoSlot(slot);
#endif

    {
        char msg[96];
        snprintf(msg, sizeof(msg), "REMIND:%u,%s\r\n", slot, g_slots[slot].medicine_name);
        BLE_Send(msg);
    }
}

static void CheckMedicationAlarm(void)
{
    if (!System_TimeReady() || g_sys_state != SYS_IDLE) return;

    uint8_t hour = 0, minute = 0, second = 0;
    System_GetHMS(&hour, &minute, &second);

    uint16_t alarm_key = ((uint16_t)hour << 8) | minute;
    (void)second;
    if (alarm_key == last_alarm_key) return;

    for (int i = 0; i < PERIOD_COUNT; i++) {
        if (g_plans[i].enabled && g_plans[i].hour == hour && g_plans[i].minute == minute) {
            last_alarm_key = alarm_key;
            StartDispense(g_plans[i].slot_id);
            break;
        }
    }
}

static void CheckDispenseDetection(void)
{
    if (g_sys_state != SYS_DISPENSING) return;

#if FEATURE_HX711
    HX711_FilterUpdate();
    int32_t current_weight = HX711_ReadWeight();
    if ((dispense_start_weight - current_weight) > TAKE_WEIGHT_DROP_THRESHOLD) {
        MedicationRecord rec;
        rec.timestamp = System_Now();
        rec.slot_id = g_missed_slot;
        rec.taken = 1;

        Record_Add(&rec);
    BLE_SendRecord(&rec);

#if FEATURE_DEBUG_UART && !FEATURE_TJC_HMI
        DebugUart_Printf("[TAKEN] slot=%u ts=%lu\r\n",
                         rec.slot_id, (unsigned long)rec.timestamp);
#endif
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

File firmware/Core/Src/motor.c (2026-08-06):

/**
 * @file    motor.c
 * @brief   TB6560 + NEMA17 步进电机驱动 — 实现
 *
 * TIM2 配置为 PWM 输出，频率 10kHz
 * 定时器计数周期 = 72MHz / 10kHz = 7200
 * 每个 PWM 脉冲 = 电机一步（含 TB6560 细分）
 */

#include "main.h"
#include "pinmap.h"
#include "motor.h"

static TIM_HandleTypeDef motor_tim;

/* 当前位置（绝对步数，以校准零位为原点） */
static volatile int32_t motor_pos = 0;

/* 零位是否已校准 */
static volatile bool motor_homed = false;

/* 每仓步数（16细分后） */
#define STEPS_PER_SLOT  (MOTOR_STEPS_PER_REV / NUM_SLOTS)
/* 校准慢转速度：500Hz */
#define HOME_STEP_FREQ  500

/* ==================== 初始化 ==================== */

void Motor_Init(void)
{
    /* GPIO 时钟 */
    __HAL_RCC_GPIOA_CLK_ENABLE();
    __HAL_RCC_TIM2_CLK_ENABLE();

    /* ---- PA0 = TIM2_CH1 (PUL PWM) ---- */
    GPIO_InitTypeDef gpio = {0};
    gpio.Mode  = GPIO_MODE_AF_PP;
    gpio.Pull  = GPIO_NOPULL;
    gpio.Speed = GPIO_SPEED_FREQ_HIGH;
    gpio.Pin   = MOTOR_PUL_PIN;
    HAL_GPIO_Init(MOTOR_PUL_PORT, &gpio);

    /* ---- PA1 = DIR, PA4 = EN ---- */
    gpio.Mode  = GPIO_MODE_OUTPUT_PP;
    gpio.Speed = GPIO_SPEED_FREQ_LOW;

    gpio.Pin   = MOTOR_DIR_PIN;
    HAL_GPIO_Init(MOTOR_DIR_PORT, &gpio);

    gpio.Pin   = MOTOR_EN_PIN;
    HAL_GPIO_Init(MOTOR_EN_PORT, &gpio);

    /* 初始状态：禁能、方向 CW */
    HAL_GPIO_WritePin(MOTOR_DIR_PORT, MOTOR_DIR_PIN, GPIO_PIN_RESET);
    HAL_GPIO_WritePin(MOTOR_EN_PORT,  MOTOR_EN_PIN,  GPIO_PIN_SET); /* HIGH=禁能 */

    /* ---- TIM2 PWM ---- */
    motor_tim.Instance               = MOTOR_TIM;
    motor_tim.Init.Prescaler         = 0;            /* 不分频 */
    motor_tim.Init.CounterMode       = TIM_COUNTERMODE_UP;
    motor_tim.Init.Period            = 7200 - 1;     /* 72M / 7200 = 10kHz */
    motor_tim.Init.ClockDivision     = TIM_CLOCKDIVISION_DIV1;
    motor_tim.Init.AutoReloadPreload = TIM_AUTORELOAD_PRELOAD_ENABLE;
    HAL_TIM_PWM_Init(&motor_tim);

    /* PWM 输出通道：占空比 50% */
    TIM_OC_InitTypeDef oc = {0};
    oc.OCMode     = TIM_OCMODE_PWM1;
    oc.Pulse      = 3600;  /* 50% duty */
    oc.OCPolarity = TIM_OCPOLARITY_HIGH;
    oc.OCFastMode = TIM_OCFAST_DISABLE;
    HAL_TIM_PWM_ConfigChannel(&motor_tim, &oc, MOTOR_TIM_CHANNEL);

    /* 初始不输出 PWM */
    HAL_TIM_PWM_Stop(&motor_tim, MOTOR_TIM_CHANNEL);
}

/* ==================== 基本控制 ==================== */

void Motor_Enable(void)
{
    HAL_GPIO_WritePin(MOTOR_EN_PORT, MOTOR_EN_PIN, GPIO_PIN_RESET); /* LOW=使能 */
}

void Motor_Disable(void)
{
    HAL_GPIO_WritePin(MOTOR_EN_PORT, MOTOR_EN_PIN, GPIO_PIN_SET); /* HIGH=禁能 */
}

void Motor_SetDir(MotorDir dir)
{
    HAL_GPIO_WritePin(MOTOR_DIR_PORT, MOTOR_DIR_PIN,
                      (dir == DIR_CW) ? GPIO_PIN_RESET : GPIO_PIN_SET);
}

void Motor_Stop(void)
{
    HAL_TIM_PWM_Stop(&motor_tim, MOTOR_TIM_CHANNEL);
}

/* ==================== 步进控制 ==================== */

void Motor_Step(uint32_t steps, MotorDir dir)
{
    if (steps == 0) return;

    Motor_Enable();
    Motor_SetDir(dir);

    /* 重新配置定时器周期以控制速度（默认 10kHz = 最大速度） */
    __HAL_TIM_SET_AUTORELOAD(&motor_tim, 7200 - 1);
    __HAL_TIM_SET_COMPARE(&motor_tim, MOTOR_TIM_CHANNEL, 3600);

    /* 启动 PWM 输出 */
    HAL_TIM_PWM_Start(&motor_tim, MOTOR_TIM_CHANNEL);

    /* 用定时器更新中断计数步数 */
    /* 简单实现：用滴答定时器延时估算（每步 100us @ 10kHz） */
    uint32_t delay_us = steps * 100;  /* 100us/步 @ 10kHz */
    if (delay_us < 1000) delay_us = 1000;

    /* 分块延时避免看门狗 */
    while (delay_us > 0) {
        uint32_t chunk = (delay_us > 50000) ? 50000 : delay_us;
        HAL_Delay(chunk / 1000);
        if (chunk < 1000) {
            /* 微秒级：用空循环 */
            for (volatile uint32_t i = 0; i < chunk * 10; i++) { __NOP(); }
        }
        delay_us -= chunk;
    }

    HAL_TIM_PWM_Stop(&motor_tim, MOTOR_TIM_CHANNEL);

    /* 更新位置 */
    int32_t delta = (dir == DIR_CW) ? (int32_t)steps : -(int32_t)steps;
    motor_pos += delta;
}

void Motor_GotoSlot(uint8_t slot)
{
    if (slot >= NUM_SLOTS) return;
    if (!motor_homed) {
        Motor_CalibrateHome();
        if (!motor_homed) return;
    }

    /* 计算目标位置（每个仓 60° = STEPS_PER_SLOT 步） */
    int32_t target = (int32_t)slot * STEPS_PER_SLOT;
    int32_t diff = target - motor_pos;

    /* 最短路径 */
    if (diff > MOTOR_STEPS_PER_REV / 2) {
        diff -= MOTOR_STEPS_PER_REV;
    } else if (diff < -MOTOR_STEPS_PER_REV / 2) {
        diff += MOTOR_STEPS_PER_REV;
    }

    MotorDir dir = (diff >= 0) ? DIR_CW : DIR_CCW;
    Motor_Step((uint32_t)(diff >= 0 ? diff : -diff), dir);
}

/* ==================== 零位校准 ==================== */

int Motor_CalibrateHome(void)
{
    Motor_Enable();

    /* 先慢转一整圈找零位传感器（OPTICAL2 = PB13） */
    /* 降低 PWM 频率到 500Hz 以便检测 */
    __HAL_TIM_SET_AUTORELOAD(&motor_tim, (72000000 / HOME_STEP_FREQ) - 1);
    __HAL_TIM_SET_COMPARE(&motor_tim, MOTOR_TIM_CHANNEL,
                          (72000000 / HOME_STEP_FREQ) / 2);

    HAL_TIM_PWM_Start(&motor_tim, MOTOR_TIM_CHANNEL);

    uint32_t max_steps = MOTOR_STEPS_PER_REV + 200;  /* 一圈多一点点 */
    bool found = false;

    for (uint32_t i = 0; i < max_steps; i++) {
        /* 检测零位传感器：LOW = 被遮挡（到达零位标记） */
        if (HAL_GPIO_ReadPin(OPTICAL2_PORT, OPTICAL2_PIN) == GPIO_PIN_RESET) {
            /* 去抖：再走 5 步确认 */
            HAL_Delay(2);
            if (HAL_GPIO_ReadPin(OPTICAL2_PORT, OPTICAL2_PIN) == GPIO_PIN_RESET) {
                found = true;
                break;
            }
        }
        HAL_Delay(1);  /* ~1ms/步 @ 500Hz */
    }

    HAL_TIM_PWM_Stop(&motor_tim, MOTOR_TIM_CHANNEL);

    if (!found) {
        /* 恢复默认速度 */
        __HAL_TIM_SET_AUTORELOAD(&motor_tim, 7200 - 1);
        Motor_Disable();
        return -1;
    }

    /* 零位基准 */
    motor_pos  = 0;
    motor_homed = true;

    /* 恢复默认速度 */
    __HAL_TIM_SET_AUTORELOAD(&motor_tim, 7200 - 1);
    __HAL_TIM_SET_COMPARE(&motor_tim, MOTOR_TIM_CHANNEL, 3600);
    Motor_Disable();

    return 0;
}

int32_t Motor_GetPosition(void)
{
    return motor_pos;
}

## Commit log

2026-08-06 feat: publish smart pillbox prototype
    [smart_pillbox_base_lightweight_with_screen_opening.stl, smart_pillbox_colored_internal_no_lid.step, smart_pillbox_colored_product_render.step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]
2026-09-05 docs: 更新项目说明与功能配置
2026-09-05 docs: 在 README 补充产品图片说明
